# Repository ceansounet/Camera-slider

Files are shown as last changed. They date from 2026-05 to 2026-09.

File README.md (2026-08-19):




# Camera-Slider
This project is a camera slider, useful to take smooth video shots, long moving timelapses, repeatable movement for special effect shots and much more.

## Features : 
- 2 motors for translation and rotation
- Compatible with phone control and a custom controller
- Saving points and playing them back
- Custom speed curves
- A ton of possible shots : timelapse, special FX overlaying, object tracking.
- usb-c charging for both, the slider is compatible with any usb-c battery bank (~20W peak)

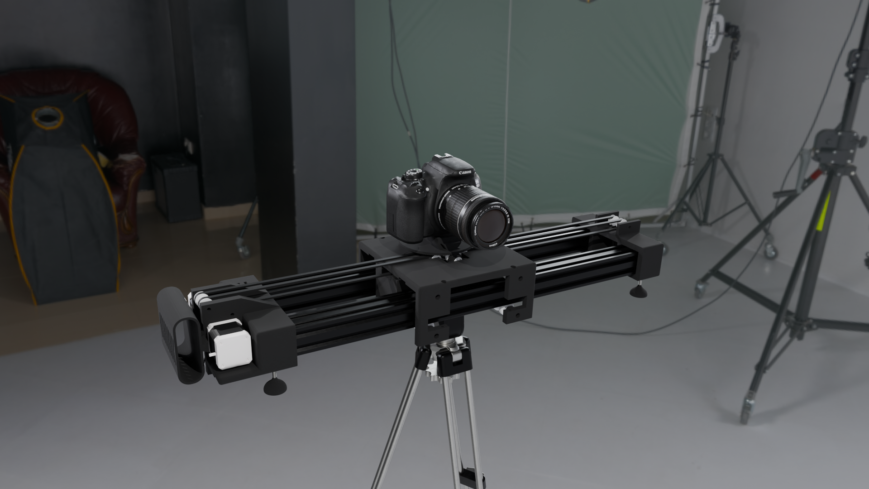
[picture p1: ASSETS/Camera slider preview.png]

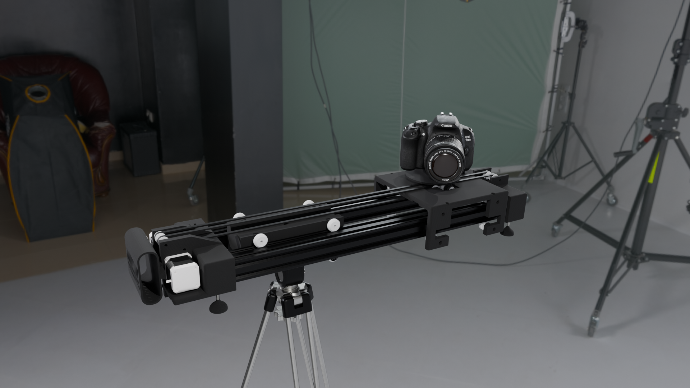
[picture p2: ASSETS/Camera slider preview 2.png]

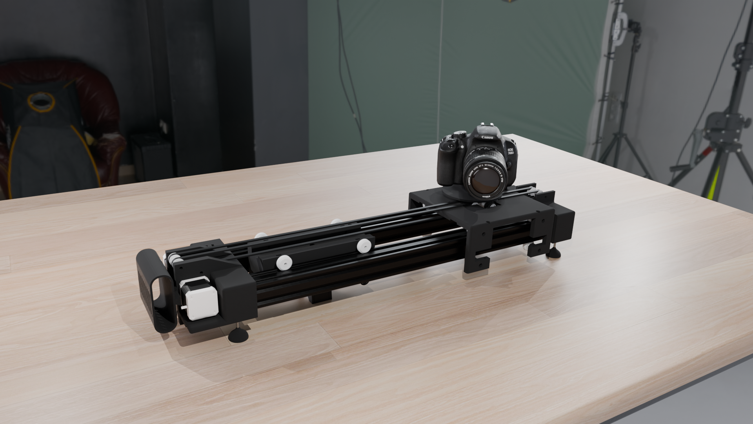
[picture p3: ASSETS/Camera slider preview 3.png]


## Workflow :
- connect
- Set 2 points or more by hand
- choose speed curves (or leave the default one)
- choose the kind of shot wanted
- start recording
- press play

## here is a youtube playlist with all of my work sessions :
[Camera-Slider Playlist](https://www.youtube.com/watch?v=zh-EyJo-g44&list=PLc9wTLk_Nb17q8Yq_pcCUll0olrOZS_lk&pp=0gcJCcwEOCosWNinsAgC)

Main CAD file :



Cut view of the slider :



PCB for the slider :



Controller CAD :



Main PCB for the controller :



Second controller PCB : 



Exploded shot GIF for Assembly : 

## Tech used :

CAD - Solidworks + Grabcad

PCB - Kicad

Code - VScode + ESP IDF addon

## Videos and pictures of the build :



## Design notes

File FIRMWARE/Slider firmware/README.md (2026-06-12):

# MotionCtrl — Firmware ESP32-S3

Contrôleur de 2 moteurs pas-à-pas (A4988) avec interface web WiFi et manette déportée.

---

## Architecture

```
motionctrl/              ← Firmware unité principale
├── main/
│   ├── main.c           ← Point d'entrée, init, boucle watchdog
│   └── config.h         ← Tous les pins & constantes
└── components/
    ├── stepper/         ← Driver A4988 (esp_timer ISR, rampe accél)
    ├── motion_planner/  ← Points, séquences, effets, NVS
    ├── wifi_ap/         ← Point d'accès WiFi
    ├── webserver/       ← HTTP + WebSocket, UI embarquée
    └── controller_link/ ← UART vers manette (JSON framé)

motionctrl_controller/   ← Firmware manette
└── main/main.c          ← Joysticks, boutons, écran, UART
```

---

## Câblage unité principale

| Signal | GPIO |
|---|---|
| M1 DIR | 1 |
| M1 STEP | 2 |
| M1 ENABLE | 3 |
| M2 DIR | 4 |
| M2 STEP | 5 |
| M2 ENABLE | 6 |
| ENDSTOP | 13 |
| UART TX → manette | 17 |
| UART RX ← manette | 18 |

> A4988 : ENABLE actif à l'état BAS. Le firmware gère le HIGH/LOW automatiquement.
> ENDSTOP : connecte la broche à GND quand déclenché (pull-up interne activé).

---

## Câblage manette (ESP32-S3)

| Signal | GPIO |
|---|---|
| Joystick 1 X | 1 (ADC1_CH0) |
| Joystick 1 BTN | 3 |
| Joystick 2 X | 4 (ADC1_CH3) |
| Joystick 2 BTN | 6 |
| BTN STOP | 7  |
| BTN HOME | 8  |
| BTN RUN | 9  |
| BTN MENU | 16 |
| UART TX → principale | 17 |
| UART RX ← principale | 18 |
| Écran BL PWM | 15 |
| Écran SPI MOSI | 11 |
| Écran SPI SCLK | 12 |
| Écran CS | 10 |
| Écran DC | 13 |
| Écran RST | 14 |

---

## Compilation et flash

### Prérequis
- ESP-IDF v5.1+
- `idf.py` dans le PATH

### Unité principale
```bash
cd motionctrl
idf.py set-target esp32s3
idf.py build
idf.py -p /dev/ttyUSB0 flash monitor
```

### Manette
```bash
cd motionctrl_controller
idf.py set-target esp32s3
idf.py build
idf.py -p /dev/ttyUSB1 flash monitor
```

---

## Utilisation

1. **Allumer l'unité principale** → crée le réseau WiFi `MotionCtrl` (mdp: `motionctrl123`)
2. **Connecter le téléphone** à ce réseau
3. **Ouvrir** http://192.168.4.1 dans le navigateur

### Interface web – onglets

| Onglet | Fonctionnalité |
|---|---|
| **Jog** | Déplacement manuel moteur par moteur, homing, enable/disable |
| **Points** | Sauvegarder la position courante, lister, naviguer, supprimer |
| **Séquence** | Ajouter des points dans un ordre, choisir vitesse/pause/courbe d'accélération, lancer/pause/stop |
| **Effets** | Hyperlapse, Oscillation, Pendulum – configurer et lancer |

### Courbes d'accélération disponibles
- **Linéaire** : rampe constante
- **Ease In** : démarrage doux, freinage brusque
- **Ease Out** : démarrage brusque, freinage doux
- **Ease In/Out** : courbe S symétrique
- **Bézier** : smooth step (smoothstep cubique)

### Effets
| Effet | Description |
|---|---|
| **Hyperlapse** | Déplace en N positions équidistantes entre A et B, avec pause configurable entre chaque → parfait pour timelapse |
| **Oscillation** | Fait des allers-retours entre deux points, avec pause aux extrémités |
| **Pendulum** | Mouvement sinusoïdal entre deux points, vitesse variable naturellement |

### Manette physique
| Contrôle | Action |
|---|---|
| Joystick 1 | Jog Moteur 1 (proportionnel) |
| Joystick 2 | Jog Moteur 2 (proportionnel) |
| BTN STOP | Arrêt immédiat des moteurs |
| BTN HOME | Homing Moteur 1 |
| BTN RUN | Lancer la séquence |
| BTN MENU | Changer d'écran |
| JOY1 BTN  | Pause / Reprendre |

---

## Personnalisation

### Mécanique (config.h)
```c
#define DEFAULT_STEPS_PER_MM    80     // steps/mm selon votre mécanique
#define DEFAULT_MAX_SPEED_MM_S  100.0  // vitesse max mm/s
#define DEFAULT_ACCEL_MM_S2     200.0  // accélération mm/s²
```

### Changer le mot de passe WiFi
```c
#define WIFI_AP_PASS  "votre_mot_de_passe"
```

### Ajouter un driver d'écran (manette)
Remplacer la fonction `display_render()` dans `motionctrl_controller/main/main.c` par votre driver LCD (LVGL, TFT_eSPI, esp_lcd, etc.).

---

## Protocole UART (unité principale ↔ manette)

Frame : `[STX=0x02][LEN_HI][LEN_LO][JSON][ETX=0x03]`

### Commandes → unité principale
```json
{"cmd":"J","motor":0,"steps":100,"speed":10.0}   // Jog
{"cmd":"S"}                                        // Stop
{"cmd":"H","motor":0}                              // Home
{"cmd":"G","idx":2,"speed":15.0}                   // Goto point
{"cmd":"R"}                                        // Run sequence
{"cmd":"P"}                                        // Pause
{"cmd":"r"}                                        // Resume
```

### Status ← unité principale (push 200ms)
```json
{"state":"idle","m1_pos":1234,"m1_run":false,"m2_pos":567,"m2_run":false,"endstop":false}
```

---

## Notes importantes

- **Endstop** : le firmware déclenche un `stepper_stop_all()` sur interruption GPIO (front descendant). Si vous utilisez l'endstop pour le homing uniquement, vous pouvez retirer l'ISR dans `main.c`.
- **Microstepping** : le firmware compte en steps bruts. Ajustez `DEFAULT_STEPS_PER_MM` selon votre microstepping (1/16, 1/8, etc.).
- **La persistance NVS** sauvegarde automatiquement les points et séquences — ils survivent aux redémarrages.
- **Sécurité** : pas d'authentification sur l'interface web (réseau local isolé).

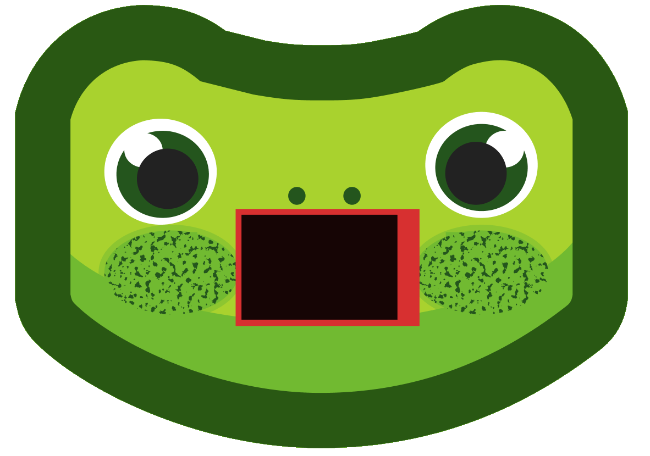
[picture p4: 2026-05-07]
ASSETS/FROG STICKER.png

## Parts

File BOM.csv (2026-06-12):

Item | Description | Quantity | Unit Price | Shipping | Total price | Total price ($) | product link
Nema 17 stepper motor | 17HE19-2004S from stepper online | 2 | 8,64€ | 9,29€ | 26,57€ | $30,75 | Série E Nema 17 Bipolaire 55Ncm(77.88oz.in) 2A 42x48mm 4 Fils avec 1m Câble & Connecteur - 17HE19-2004S|STEPPERONLINE
Aluminium extrusions | 1m double V-slot 4040 | 2 | 27,68€ | 14,12€ | 69,48€ | $80,40 | Profilé aluminium V-SLOT 40x40 fente 6 mm - Anodisé noir
Battery bank | 12v 1,5 amps minimum, any will do | 1 | 19,99€ | 0€ | 19,99€ | $23,13 | VARMFRONT chargeur mobile universel, bleu foncé, 10400 mAh - IKEA
18650 li ion batterie | 3,6v 3180mAh | 2 | 3,29€ | 4,10€ | 10,68€ | $12,36 | Panasonic NCR18650BD 3180mAh - 10A
12v to 5v Buck converter | for the slider control board | 1 | 2,79€ | 0€ | 2,79€ | $3,23 | https://www.aliexpress.com/item/1005006151233979.html?mp=1
3,5 inch TFT screen | screen, non touch | 1 | 8,89€ | 0€ | 8,89€ | $10,29 | https://www.aliexpress.com/item/1005004903996715.html?mp=1
Joystick | XY joysticks to control the slider | 2 | 1,71€ | 0€ | 3,42€ | $3,96 | https://www.aliexpress.com/item/1005007039932732.html?mp=1
ESP32 S3 supermini | Dev boards | 2 | 4,49€ | 0€ | 8,98€ | $10,39 | https://www.aliexpress.com/item/1005007941259180.html?mp=1
IO expander | MCP 23017 | 1 | 2,17€ | 0€ | 2,17€ | $2,51 | https://www.aliexpress.com/item/1005008066849865.html?mp=1
Cherry MX switches | 10 pack of gateron yellow 3.0 | 1 | 3,19€ | 0€ | 3,19€ | $3,69 | https://www.aliexpress.com/item/1005006376024657.html?mp=1
USB PD board | for 12v power | 1 | 4,59€ | 0€ | 4,59€ | $5,31 | https://www.aliexpress.com/item/1005008209411188.html?mp=1
M5 locknuts | 25 pack | 1 | 1,89€ | 0€ | 1,89€ | $2,19 | https://www.aliexpress.com/item/32798773566.html?mp=1
v-slot wheels | 24 pack (only need 16) | 1 | 17,69€ | 0€ | 17,69€ | $20,47 | https://www.aliexpress.com/item/1005005890959821.html?mp=1
M4*90mm | 10 pack (only need 4) | 1 | 4,49€ | 0€ | 4,49€ | $5,20 | https://www.aliexpress.com/item/1005002270744409.html?mp=1
End stop switch | 10 pack, only need 1 | 1 | 1,59€ | 0€ | 1,59€ | $1,84 | https://www.aliexpress.com/item/32939882024.html?mp=1
Ball bearings | 10 pack, only need 4 | 1 | 3,89€ | 0€ | 3,89€ | $4,50 | https://www.aliexpress.com/item/1005007668446060.html?mp=1
GT2 Idler Pulley | 2*6 pack, need 10 | 2 | 5,79€ | 0€ | 11,58€ | $13,40 | https://www.aliexpress.com/item/1005007557987612.html?mp=1
GT2 teethed pulley | 5 pack, only need 3 | 1 | 3,19€ | 0€ | 3,19€ | $3,69 | https://www.aliexpress.com/item/32781681772.html?mp=1
1/4" nut | 20 pack, need 1 | 1 | 4,09€ | 0€ | 4,09€ | $4,73 | https://www.aliexpress.com/item/1005009774349007.html?mp=1
GT2 belt | 5 meters 6mm | 1 | 11,69€ | 0€ | 11,69€ | $13,53 | https://www.aliexpress.com/item/1005010116034089.html?mp=1
1/2" 1/4" screw | UNC screws, for camera, only need 1 | 1 | 2,09€ | 0€ | 2,09€ | $2,42 | https://www.aliexpress.com/item/1005005237204588.html?mp=1
2" 1/4" screw | UNC screws, for tripod, only need 1 | 1 | 4,09€ | 0€ | 4,09€ | $4,73 | https://www.aliexpress.com/item/1005005237204588.html?mp=1
1/4" 50mm coupling nut | UNC nut, for tripod | 1 | 6,79€ | 2,09€ | 8,88€ | $10,28 | https://www.aliexpress.com/item/1005008622413040.html?mp=1
Battery holder | 2 parallel battery holder | 1 | 1,49€ | 0,00€ | 1,49€ | $1,72 | https://www.aliexpress.com/item/1005003099571328.html?mp=1
Main slider PCB | pack of 5, need 1 | 1 | 1,73€ | 8,48€ | 10,21€ | $11,81 | https://cart.jlcpcb.com/shopcart/cart
Main controller PCB | pack of 5, need 1 | 1 | 3,46€ | 0€ | 3,46€ | $4,00 | https://cart.jlcpcb.com/shopcart/cart
Controller keys PCB | pack of 5, need 2 | 1 | 3,46€ | 0€ | 3,46€ | $4,00 | https://cart.jlcpcb.com/shopcart/cart
Resistors | 4.7Kohm | 2 | 0€ | 0€ | 0,00€ | $0,00 | I already have those but you can find them anywhere on aliexpress
Capacitor | 100nF decoupling cap for the IO expander | 1 | 0€ | 0€ | 0,00€ | $0,00 | I already have those but you can find them anywhere on aliexpress
Capacitor | 100uF decoupling cap for the motors | 1 | 1,83€ | 0€ | 1,83€ | $2,12 | 10V 16V 25V 35V 50V 400V 450V DIP Aluminum Electrolytic Capacitor 100UF 220UF 330UF 470UF 680UF 1000UF 10UF 22UF 47UF 0.47UF - AliExpress 502
Elegoo PLA Matte | ~500g | 1 | 17,99€ | 15€ | 32,99€ | $38,18 | ELEGOO PLA MATTE Filament 1.75mm Colored 1KG
Elegoo PETG rapid | ~1,3kg, rolls of 1kg | 2 | 13,99€ | 0€ | 27,98€ | $32,38 | RAPID PETG – ELEGOO FR
TOTAL : |  |  |  |  | 256,36€ | $296,66

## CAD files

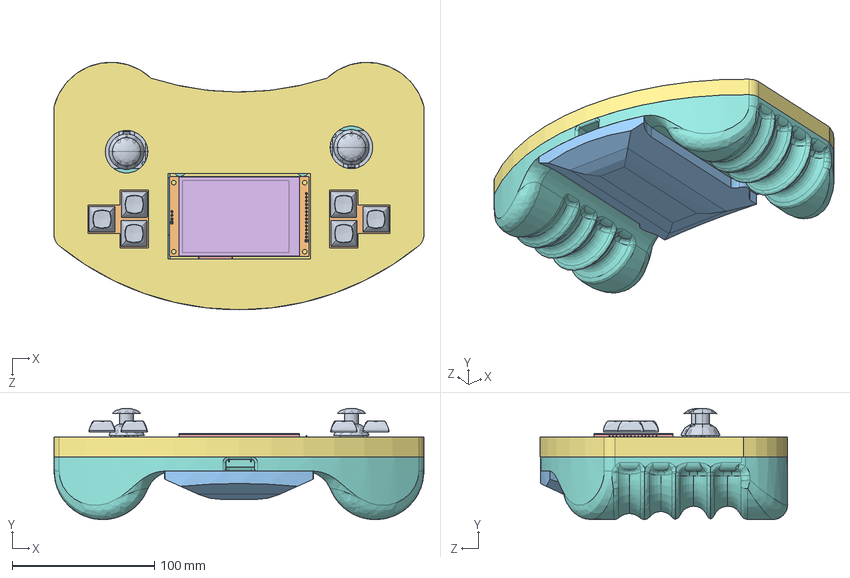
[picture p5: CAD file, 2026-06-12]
CAD/Full controller assembly.STEP
260.0 x 78.2 x 173.9 mm
PinHeader_1x04_P2.54mm_Vertical_1.step x 2
PinHeader_1x05_P2.54mm_Vertical.step x 2
C_Disc_D5.0mm_W2.5mm_P5.00mm.step
DIP-28_W7.62mm.step
PinHeader_1x09_P2.54mm_Vertical.step x 2
R_Axial_DIN0207_L6.3mm_D2.5mm_P7.62mm_Horizontal.step x 2
controller_PCB.step
Case bas^controller
Joystick HW504 Board_Varsayılan x 2
TFT SPI Serial LCD Module 480X320 Driver IC ILI9488_XPT2046_MSP3520_По умолчанию
card sd_Valor predeterminado
microSDCard_По умолчанию
contact01.step_По умолчанию
contact02.step_По умолчанию
contact03.step_По умолчанию
contact04.step_По умолчанию
contact05.step_По умолчанию
contact06.step_По умолчанию
contact07.step_По умолчанию
contact08.step_По умолчанию
frame.step_По умолчанию
contact09.step_По умолчанию
cover.step_По умолчанию
contact11.step_По умолчанию
contact10.step_По умолчанию
Штыревой разъем 14 конт шаг 2.54мм_По умолчанию
screen spacer^controller x 4
Top cover^controller
MX Mount v1.step x 6
eBom-FreeParts.step x 6
PinHeader_1x04_P2.54mm_Vertical.step x 2
keys_PCB.step x 2
Back cover^controller

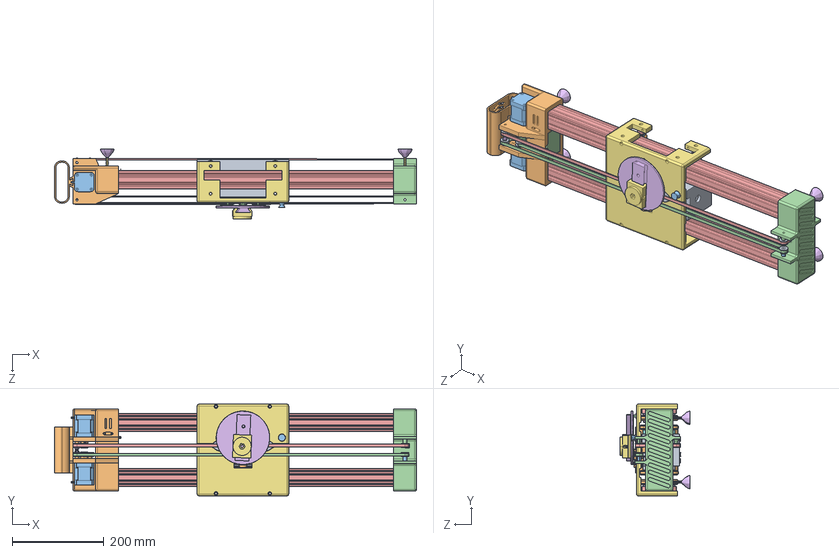
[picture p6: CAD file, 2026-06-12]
CAD/Full slider assembly.STEP
790.0 x 200.0 x 152.5 mm
Left End cap^slider assembly
Right end cap^slider assembly
Camera carriage^slider assembly_Défaut<Brut d''usinage>
Under carriage tripod mount^slider assembly
Solid V-Wheel.stp x 16
Ball Bearing 625 2RS 5x16x5.stp x 32
1mm 5mm shim.stp x 16
aluminium 4040 vslot Extrusions^slider assembly_Défaut<Brut d''usinage>
M5 Nylock.ipt x 4
1-4-20unc nut_95462A029
¼-20 x 1.ipt
GT2 sin dientes_Predeterminado x 11
GT2 Timing Pulley x 3
NEMA17_17HS19-2004S1_Stepperonline_По умолчанию x 2
Bearing 625 ZZ x 6
Copy of Bearing holder 2^Bearing assembly_slider assembly x 3
Copy of Feets^Assemblage2_slider assembly x 4
bolt x 4
M5 nut x 4
Copy of Timing belt holder^slider assembly x 4
Copy of Copy of Bearing holder 2^slider assembly
Copie (2) de Copy of Bearing holder 2^slider assembly
Bearing holder^slider assembly x 2
Bearing shim^slider assembly
Gear A^slider assembly
Camera rotary platform^slider assembly
Camera mount^slider assembly
Limit_Switch_L1
Battery holder^slider assembly
cable holder
PCB LID^slider assembly
PinHeader_1x09_P2.54mm_Vertical.step x 2
PinHeader_1x04_P2.54mm_Vertical.step x 3
PinHeader_1x02_P2.54mm_Vertical.step x 2
C_Disc_D5.0mm_W2.5mm_P5.00mm.step
SLIDER_PCB_REV_A_PCB.step
Travel lock^slider assembly
Courroie1-8^slider assembly
Courroie2-9^slider assembly

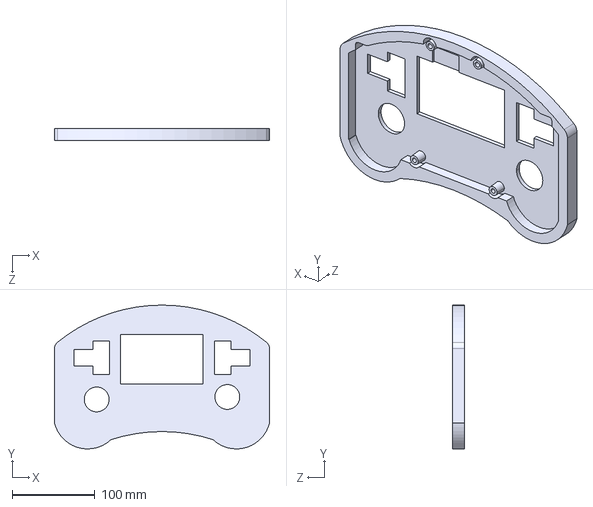
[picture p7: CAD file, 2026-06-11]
CAD/Controller/STLS/Top cover.STEP
260.0 x 173.9 x 14.0 mm

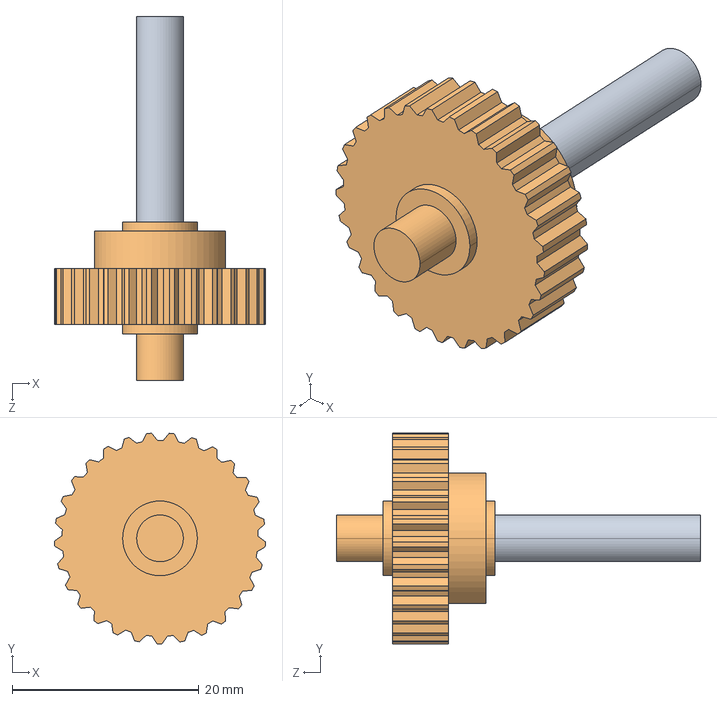
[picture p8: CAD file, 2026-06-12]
CAD/Slider/STEPs/Gear A.STEP
22.6 x 22.6 x 39.0 mm

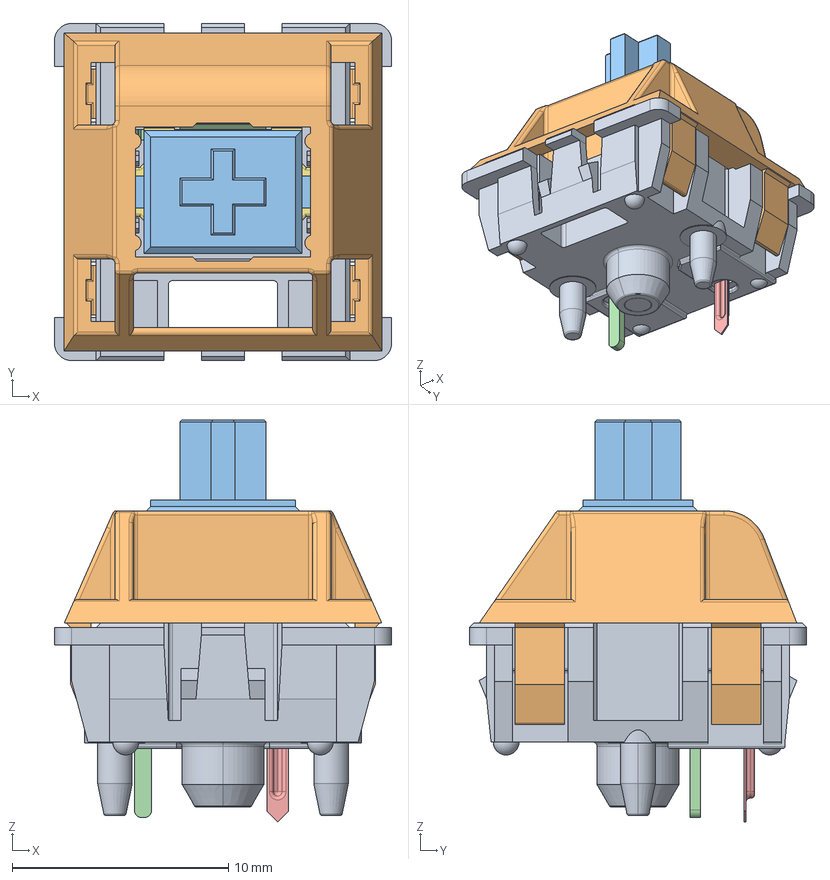
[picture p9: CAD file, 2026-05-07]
PCB/CONTROLLER_PCB_REV_A/keys/SW_Cherry_MX_1.00u_PCB.step
15.6 x 15.6 x 18.6 mm

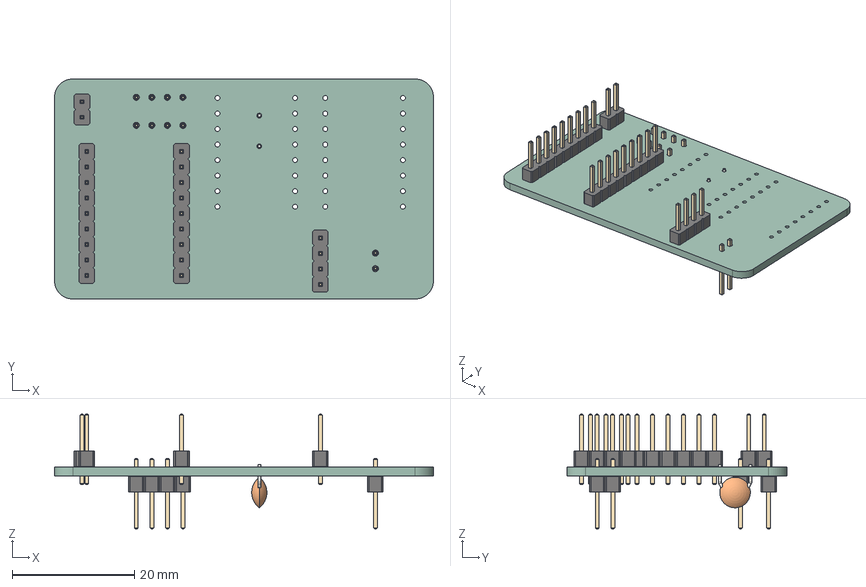
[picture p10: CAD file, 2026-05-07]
PCB/SLIDER_PCB_REV_A/SLIDER_PCB_REV_A.step
62.0 x 36.0 x 18.8 mm
PinHeader_1x09_P2.54mm_Vertical x 2
PinHeader_1x04_P2.54mm_Vertical x 3
PinHeader_1x02_P2.54mm_Vertical x 2
C_Disc_D5.0mm_W2.5mm_P5.00mm
SLIDER_PCB_REV_A_PCB

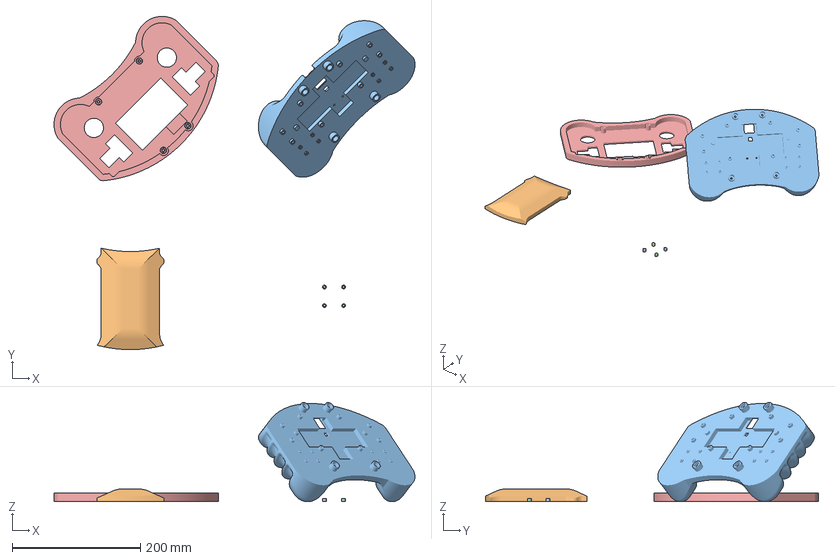
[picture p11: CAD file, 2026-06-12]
PRODUCTION/CONTROLLER 3D PRINTS/Controller prints project.3mf
562.9 x 519.6 x 155.1 mm
screen spacer x4.STEP x 4
Back cover.STEP
Case bas.STEP
Top cover.STEP

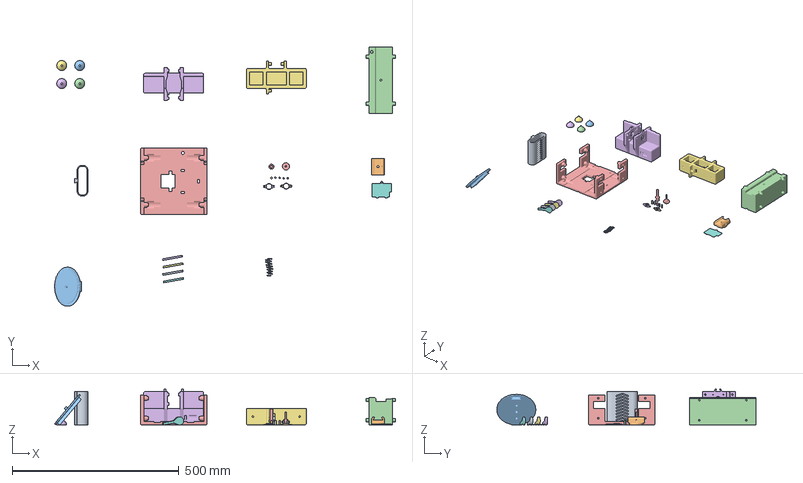
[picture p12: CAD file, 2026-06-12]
PRODUCTION/SLIDER 3D PRINTS/Slider prints project.3mf
1022.7 x 777.6 x 107.5 mm
Copy of Timing belt holder x2.STEP x 4
Bearing holder x2.STEP x 2
feets x4.STEP x 4
Travel lock.STEP
PCB LID.STEP
Battery holder.STEP
Camera mount.STEP
Camera rotary platform.STEP
Under carriage tripod mount.STEP
Camera carriage.STEP
Left End cap.STEP
Right end cap.STEP
Bearing holder little x5.STEP x 5
cable holder x14.STEP x 14
Gear A.STEP

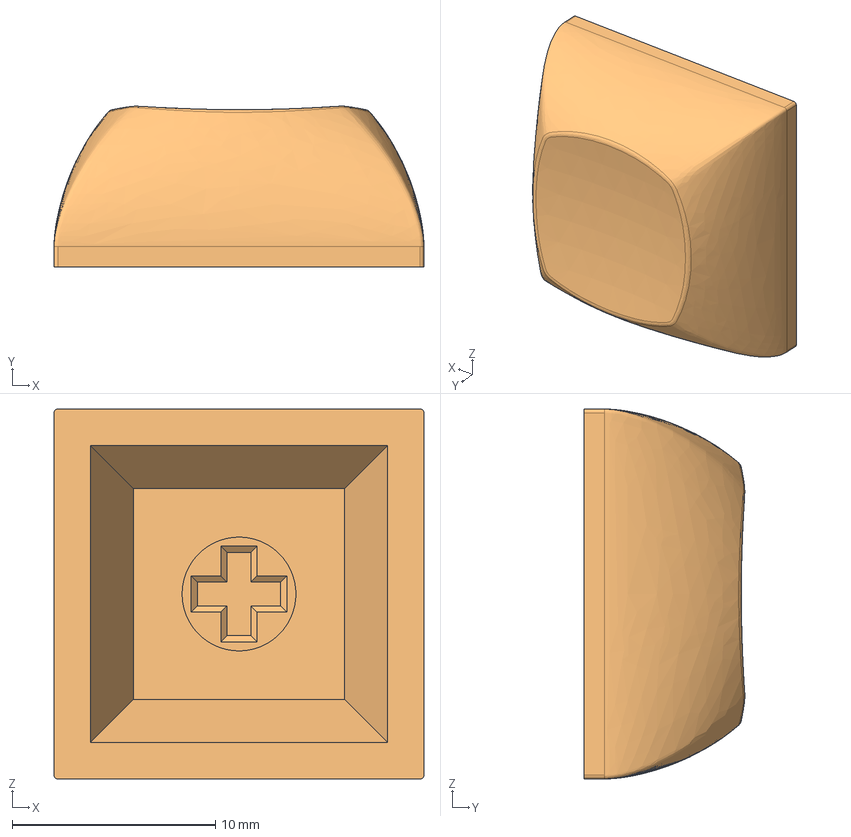
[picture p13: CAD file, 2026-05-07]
CAD/Controller/DSA 1u.step
18.2 x 7.91 x 18.2 mm

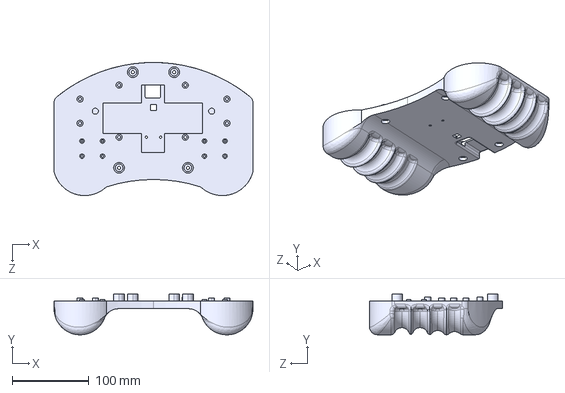
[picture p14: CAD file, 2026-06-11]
CAD/Controller/STLS/Case bas.STEP
260.0 x 53.1 x 173.9 mm

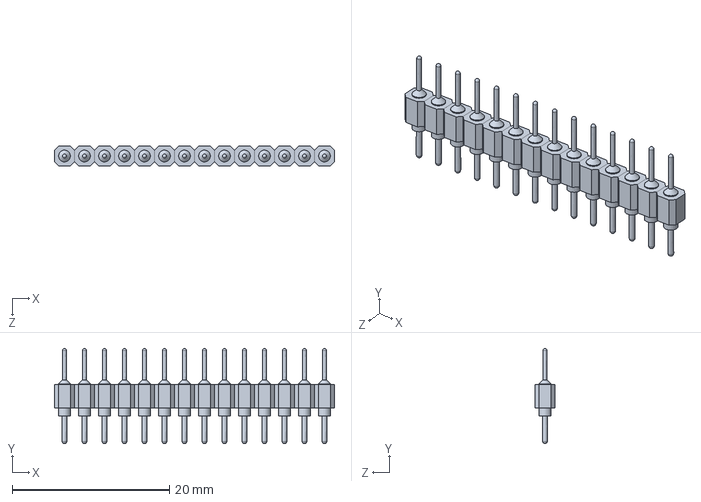
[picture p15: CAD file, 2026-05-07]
CAD/Controller/tft-spi-serial-lcd-module-480x320-driver-ic-ili9488-xpt2046-msp3520-1.snapshot.1/Штыревой разъем 14 конт шаг 2.54мм.SLDPRT
35.6 x 12.1 x 2.54 mm

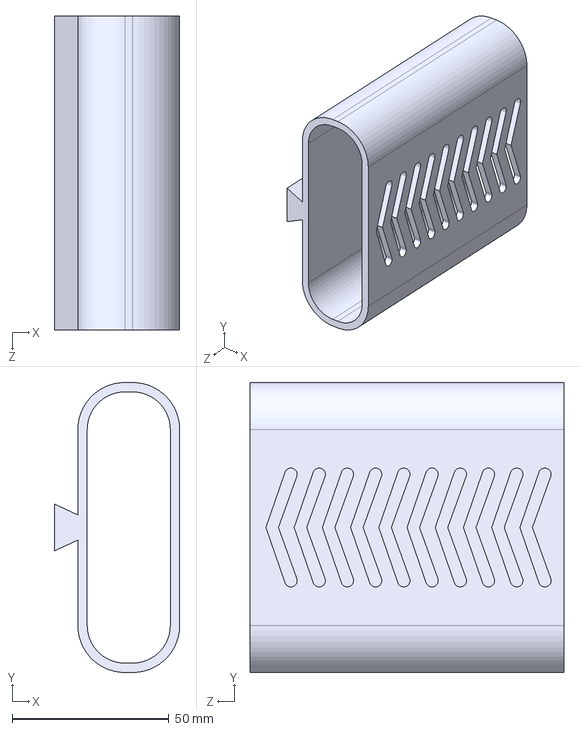
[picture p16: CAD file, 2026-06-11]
CAD/Slider/STEPs/Battery holder.STEP
40.0 x 92.5 x 100.0 mm

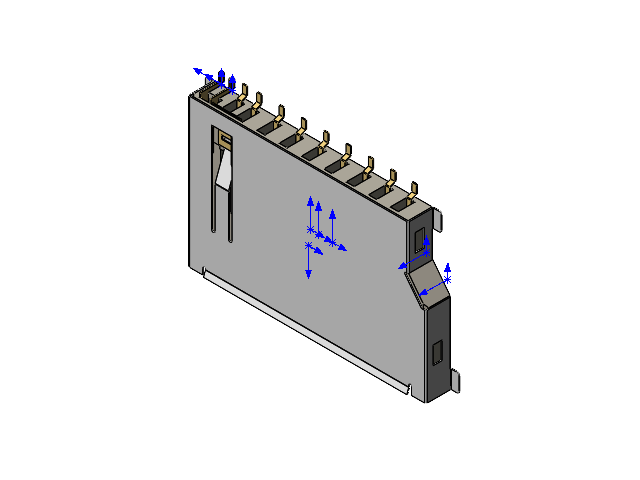
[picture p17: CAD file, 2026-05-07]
CAD/Controller/tft-spi-serial-lcd-module-480x320-driver-ic-ili9488-xpt2046-msp3520-1.snapshot.1/Slot_SD-381200-S304.SLDASM
contact01.step
contact02.step
contact03.step
contact04.step
contact05.step
contact06.step
contact07.step
contact08.step
frame.step
contact09.step
cover.step
contact11.step
contact10.step

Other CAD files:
CAD/Slider/slider assembly.SLDASM
CAD/Controller/DSA V4 1x1 v4_2.step.SLDASM
CAD/Controller/DSA V4 1x1 v4_1.step.SLDASM
CAD/Controller/MX Mount v1_2.step.SLDPRT
PCB/CONTROLLER_PCB_REV_A/controller/SW_Cherry_MX_1.00u_PCB_1.step.SLDPRT
CAD/Controller/Joystick HW504 Board.SLDPRT
CAD/Controller/MX Mount v1_1.step.SLDPRT
CAD/Controller/PinHeader_1x04_P2.54mm_Vertical_1.step.SLDPRT
CAD/Controller/STLS/Back cover.STEP
CAD/Controller/STLS/screen spacer x4.STEP
CAD/Controller/controller.SLDASM
CAD/Controller/controller.step
CAD/Controller/eBom-FreeParts_1.step.SLDPRT
CAD/Controller/eBom-FreeParts_2.step.SLDPRT
CAD/Controller/keys.step
CAD/Controller/keys_PCB_1.step.SLDPRT
CAD/Controller/tft-spi-serial-lcd-module-480x320-driver-ic-ili9488-xpt2046-msp3520-1.snapshot.1/TFT SPI Serial LCD Module 480X320 Driver IC ILI9488_XPT2046_MSP3520.SLDASM
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

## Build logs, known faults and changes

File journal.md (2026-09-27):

# May 1st, 2026: First day, started CAD !

I spent this first session doing some of the CAD for the slider assembly, this is pretty complex and I want it to be modular so I learnt a lot about global variables in solidworks, so that each parameter can be adjusted freely.
I spent a lot of time sketching for this project during class (yes, I know that I should be paying attention but philosophy is boring), so I had a pretty good idea of what I wanted to do, I looked at some existing camera sliders and either the camera couldn't rotate, or it was with an additional tool, so my idea was to combine everything into one, using of the shelf parts, instead of carbon fiber rods or weird unfindable aluminium profiles, I use simple 4040 extrusions, with double v-slots, my design is kinda inspired by eldekrone's sliderplus-v6 in the movement aspect, as it is the only one I have seen that can travel almost 2 times it's own lenght (only on a tripod) by being mounted on a moving carriage, that goes in the opposite direction as the camera.



**Total time spent: 2h17**

# May 2nd, 2026: Added feets !

In this second session I expanded on my previous design session, I made the early sketch of the under carriage that will get mounted on the tripod, and I made feets that house an M5 bolt with an embedded M5 nut, I modified the end caps accordingly to allow for those feets to screw in, and give a flexible way to adjust the slider's level.
I also took the time to adjust the main carriage's height, because it was a bit too high, and added some groves for the wheels to fit with that lowered part.



**Total time spent: 2h9**

# May 3rd, 2026: Still doing CAD !

For this short third session, I started with journaling the second session, then I did some CAD work, I added slots to insert locknuts for the v slot wheels to attach to the undercarriage.
I also did some research on how tripod screws work, so that I can attach my slider to a tripod, I want it to be extremely secure, as when it is fully extended, the forces are quite big, so I decided to go with a really long nut, a coupling nut, with a bolt on the other side to make sure it doesn't go anywhere.
I wondered about adding bolts that go through the under carriage, like in the camera carriage, to either adjust the wheels, and add a lot of strenght, but I decided against it for now, in my inspiration, the edelkrone sliderplus v6, they are present, but I am not sure if they are absolutely necessary, and I want to reduce bloat and hardware.
If I do come to regret this, I can just make another version and 3d print it again, and maybe even try a cf or gf reinforced filament.



**Total time spent: 1h13**

# May 4th, 2026: Movement, belts, the whole enchilada !

I just finished session 4, today I worked on the belt system.
I was kind of afraid of starting to work on it but as always, it wasn't too bad.
I managed to find 3d models for my stepper motors, timing and idler pulleys, both at gt2 20T 6mm, which I guess is the most common, used for 3d printers and such.
then I made a mount on one of my end caps for the motors, then for the idler pulleys. I think I will have to reinforce the different parts later on, and clean up the geometry to make it look good.



**Total time spent: 1h45**

# May 5th, 2026: Attaching the timing belts

During session 5, I added another idler pulley at the bottom, and started to work on the mounting system between the sliders and the timing belts.



**Total time spent: 1h06**

# May 6th, 2026: Attaching the timing belts again (with the bottom this time)

In this 6th session I added the slot for the GT2 6mm timing belt, and I added an attachment point for the undercarriage as well.



**Total time spent: 1h02**

# May 7th, 2026: I cooked some CAD again

In this seventh session, I designed a whole bunch of stuff :
- added/changed the rotation belt path
- added the rotation mechanism
- made the camera platform, with an added dovetail to adjust the center of mass of the camera
- made the dovetail mount
- solved a lot of small misc issues



**Total time spent: 5h02**

# May 8th, 2026: Stablizing the platform, and preparing pcb space !

During this eighth session, I added 2 bearings for stabilization under the camera platform, I then added an endstop where I will try to fit all of the electronics.
I added groves for the future PCB.
Then I added recesses for the motor wires, with little slots for cable holders.
After that was done I modeled a case for the battery, with a dovetail, and I added the opposite dovetail to the left end cap to attach it.
Seeing all of my progress, I started to work on the aestetics of my build, by adding a lot of fillets on all of the parts, and sourced 4 screws that I forgot while designing (I almost payed 10$ for 4, but I managed to find some for 5$) and I also sourced a usb-c port, and I added a slot for it on my design.






**Total time spent: 2h28**

# May 9th, 2026: Finished the CAD (1st version at least) !

In this ninth session, I pretty much finished up the CAD, did some measurements to get the lenght of GT2 belts I need, and then I moved on to the PCB, I managed to find the symbols I needed, and made a footprint for the esp.
I'm quite scared as it is going really fast, and I'm only at around the 20hr mark, I know I have some stuff left to do but I counted almost everything I need and I'm at around 170€, or exactly 200$. which is 40hrs of work, the cheapest aluminium extrusions I found are 70€ total, with shipping, and the rest of the parts add up to 100€ from aliexpress.



**Total time spent: 1h08**

# May 10th, 2026: Doing the PCB ! 

During this tenth session, I almost finished the PCB, I am still missing the routing but all of the rest is done.
I made a lid for the pcb and electronics in the cad, and I added a hole that will have a pin, used to lock the carriages together for transport.



**Total time spent: 1h47**

# May 11th, 2026: Finishing the PCB !

in this eleventh session I continued on my previous work, I finished the pcb layout and did the routing, then I finished the pin that can lock both carriages together for transport, and added magnets at the end so it's secure, and made a small storage hole for it, then I made the belts that allow the movement, and when they were done I realised that they were interfering with the usb c port location, so I moved that.




**Total time spent: 1h40**

# May 12th, 2026: Starting the controller !

This is the 12th session I believe, today I started research on the controller that I want to design, and maybe make if the budget allows, for the camera slider.
I used google and AI to do some preliminary research, while always reviewing it's claims with datasheets, forums, and common sense.
I started to source the different parts that I need, and started work on the PCB, it has a lot in common with the hackpad that I made, so I took some parts from it, but sadly this is very fast, so the plan of taking some time to design a cheap controller to have more budget for the slider isn't really going to plan...
I think the final steps of doing the github, bom, exporting everything, the zine, and most importantly the code, are vastly underestimated by myself, so there is hope that I reach the ~45-60hrs I need to finance it.
(now that I think about it, I have to code dialog between 3 esp's, and a phone, over wifi, and also make a cool interface for the website, and another one for the controller, and also code every feature by hand...)



**Total time spent: 1h16**

# May 13th, 2026: Research for the controller !

Today I did more research and planning and pcb for the controller, my previous plan kinda went overboard when I realized that the parts I was looking for kinda weren't real.
So I switched my approach to use joysticks instead, just like a drone controller.



**Total time spent: 1h11**

# May 14th, 2026: Controller PCB 

Hey, during this short 14th session I worked on the controller pcb again, I realized that pcb costs were really high for larger than 100*100mm pcb's, so I thought of a clever plan, doing 2 different pcb's, and connecting them with cables, and the second pcb will be present twice in the final build, because I get 5 per order anyway.



**Total time spent: 2h17**

# May 15th, 2026: Moved some PCB stuff around because of KiCAD

Session 15, here we go !
I continued working on the controller for the slider, I spend more time that I would like to admit on a problem, that is a limitation of kicad, every pcb has to have a project file, you can't really have 2 pcb's in a single project file.
So I had to make a new project file for the key pcb's, and modify the old one to remove the keys, so that took a while.
Then I started to work on the CAD for the controller, I exported the pcb's in step and made a sketch for the controller's over all shape. That's it for today, I don't really know how I can make it ergonomic in solidworks, but I'll try anyway. Oh and if I don't see ya, good afternoon, good evening and goodnight !



**Total time spent: 1h03**

# May 16th, 2026: Bday + Controller CAD

Session 16 ! today I celebrated my birthday, yay ! but that also means I didn't have much time to work...
Today I continued on my controller journey, I modified a bit the pcb's because they were incorrect, then I made all of the stands for the pcb's, after that was done, I found a 3d model of the screen I'm using, so I added that, and also made little standoffs so that the screen doesn't flex.
In the end I started to try and make an ergonomic shape for the controller, but that proved to be kinda hard...



**Total time spent: 1h09**

# May 17th, 2026: Ergonomics is hard ! :pf:

Session 17... this one was a bad one. I spent the whole hour fighting against solidworks to try and make ergonomic handles for the controller, they still don't look really good, but I will have to try them to see how they can be improved.



**Total time spent: 1h07**

# May 18th, 2026: Solidworks recovery, and added keycaps !

Today started on a bad note... on top of the site being down my solidworks controller assembly wouldn't open, and when it did, all of the dependencies had to be replaced, that meant also replacing every constraint :pf:.
But apart from that, I managed to make a little progress, added the keycaps, made holes for the pcb pins to have room, and for the overall controller to be slimmer, next time I can start on the top cover.



**Total time spent: 1h05**

# May 19th, 2026: Solidworks is still mad at me !

The nineteenth session started as usual with this file, with all the step files being reverted, and all of the constraints being removed, after quickly fixing that, I started work on the top part, and pretty much finished it, apart from some art that I want to make for it.
(also, it looks like a happy frog when upside down!)



**Total time spent: 1h17**

# May 20th, 2026: I'm also an artist !

20th session, :YAY: today I did some art, it's pretty mediocre but it's still art.
I made a frog sticker that goes on the controller, because I think it looks like a frog when upside down, then I made some changes to the github page, I'm still ways to the end, but I need to keep pushing, next sessions will probably be short as well, because of school stuff, but next week I have a 4 day weekend all alone, I think I can do my own hackaton and cram as many hours as possible !



**Total time spent: 1h04**

# May 21st, 2026: Boring BOM stuff

Today I worked on my BOM, and started to realise how much this project was actually gonna cost (ouch).
I also started to think about the camera head, and what I need to buy for it. (in the end, I decided to split my project, because this is too ambitious for a single project to do both, and the opensauce budget is fixed)



**Total time spent: 1h07**

# June 11th, 2026: Back to it ! 

I finally came back to this project ! I had to get back into it so I did some CAD, for the Battery pack of the controller, and I worked on the github.



**Total time spent: 2h31**

# June 12th, 2026: Submission day !

Final day (before the first submission) ! I'm basically done, I finished up the BOM, made a blender scene for the project, finished the readme, and made all of the 3d printing files for it. (about 2kg of PETG and PLA, over 50 hours and 15 build plates !)



**Total time spent: 1h54**

# July 3rd, 2026: Building

All of the parts have finally arrived, I started by cutting off a bit of the aluminium extrusions, else it wouldn't fit in my luggage to SF, then I had the painstaking process of post processing all of the printed parts, which took a while with all of the supports and the brims.
I soldered the pcbs with the components needed, but when I tried testing them, I realised both of the esp 32s that I ordered had a non functionnal antenna, which was really bad news because the whole project relied on communication between the controller and the slider, so I had to ditch the controller for now, to at least get the mechanical parts working.
Since I couldn't communicate with the pcb, I switched to an arduino uno with a cnc hat, that I had bought previously for a cnc project, that I haven't made yet, and got the 12v power from a power supply that I use for my rooms LED lighting.
I also had to splice the gt2 timing belt into a loop, which is not really meant to be done, but a custom loop this size is basically impossible to buy. so I glued them together and stiched them with nylon, and this holds properly, but the flexibility is gone, which is a problem when it gets into tight curves it can get stuck.



**Total time spent: 5h**

# July 4th, 2026: Building pt2

During the design phase, I used bolts that were non standard size, I tought, oh well, I'll figure it out on aliexpress later, and I never did, so I had about 16 m5 bolts to cut manually. I got out the hand saw, and the guide, and I got to work, it took about 5 minutes per screw, with the clean up after because the cuts were not smooth. For some other bolts were this was an option, I printed spacers and used longer screws. I also shortened the motor cables, because the space was limited, so I soldered them shorter, with some heat shrink tubes.
I inserted all of the heat set inserts inside the 3d printed parts, for the feets. I inserted all of the nuts, and added the wheels to the carriages. I then assembled the gt2 pulleys, and teethed pulleys to the motors and the gear assembly in the middle.
I also inserted the plastic holders into the bearings, and added them to the carriage.
I assembled the motors, and inserted the PCBs. Last thing was to put everything together, and test it.



**Total time spent: 2h**

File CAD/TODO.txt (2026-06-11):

TODO :
Start the BOM
add the 2 18650 batteries to the Controller CAD.
don't forget to add the voltage divider to the battery pins and the batteries

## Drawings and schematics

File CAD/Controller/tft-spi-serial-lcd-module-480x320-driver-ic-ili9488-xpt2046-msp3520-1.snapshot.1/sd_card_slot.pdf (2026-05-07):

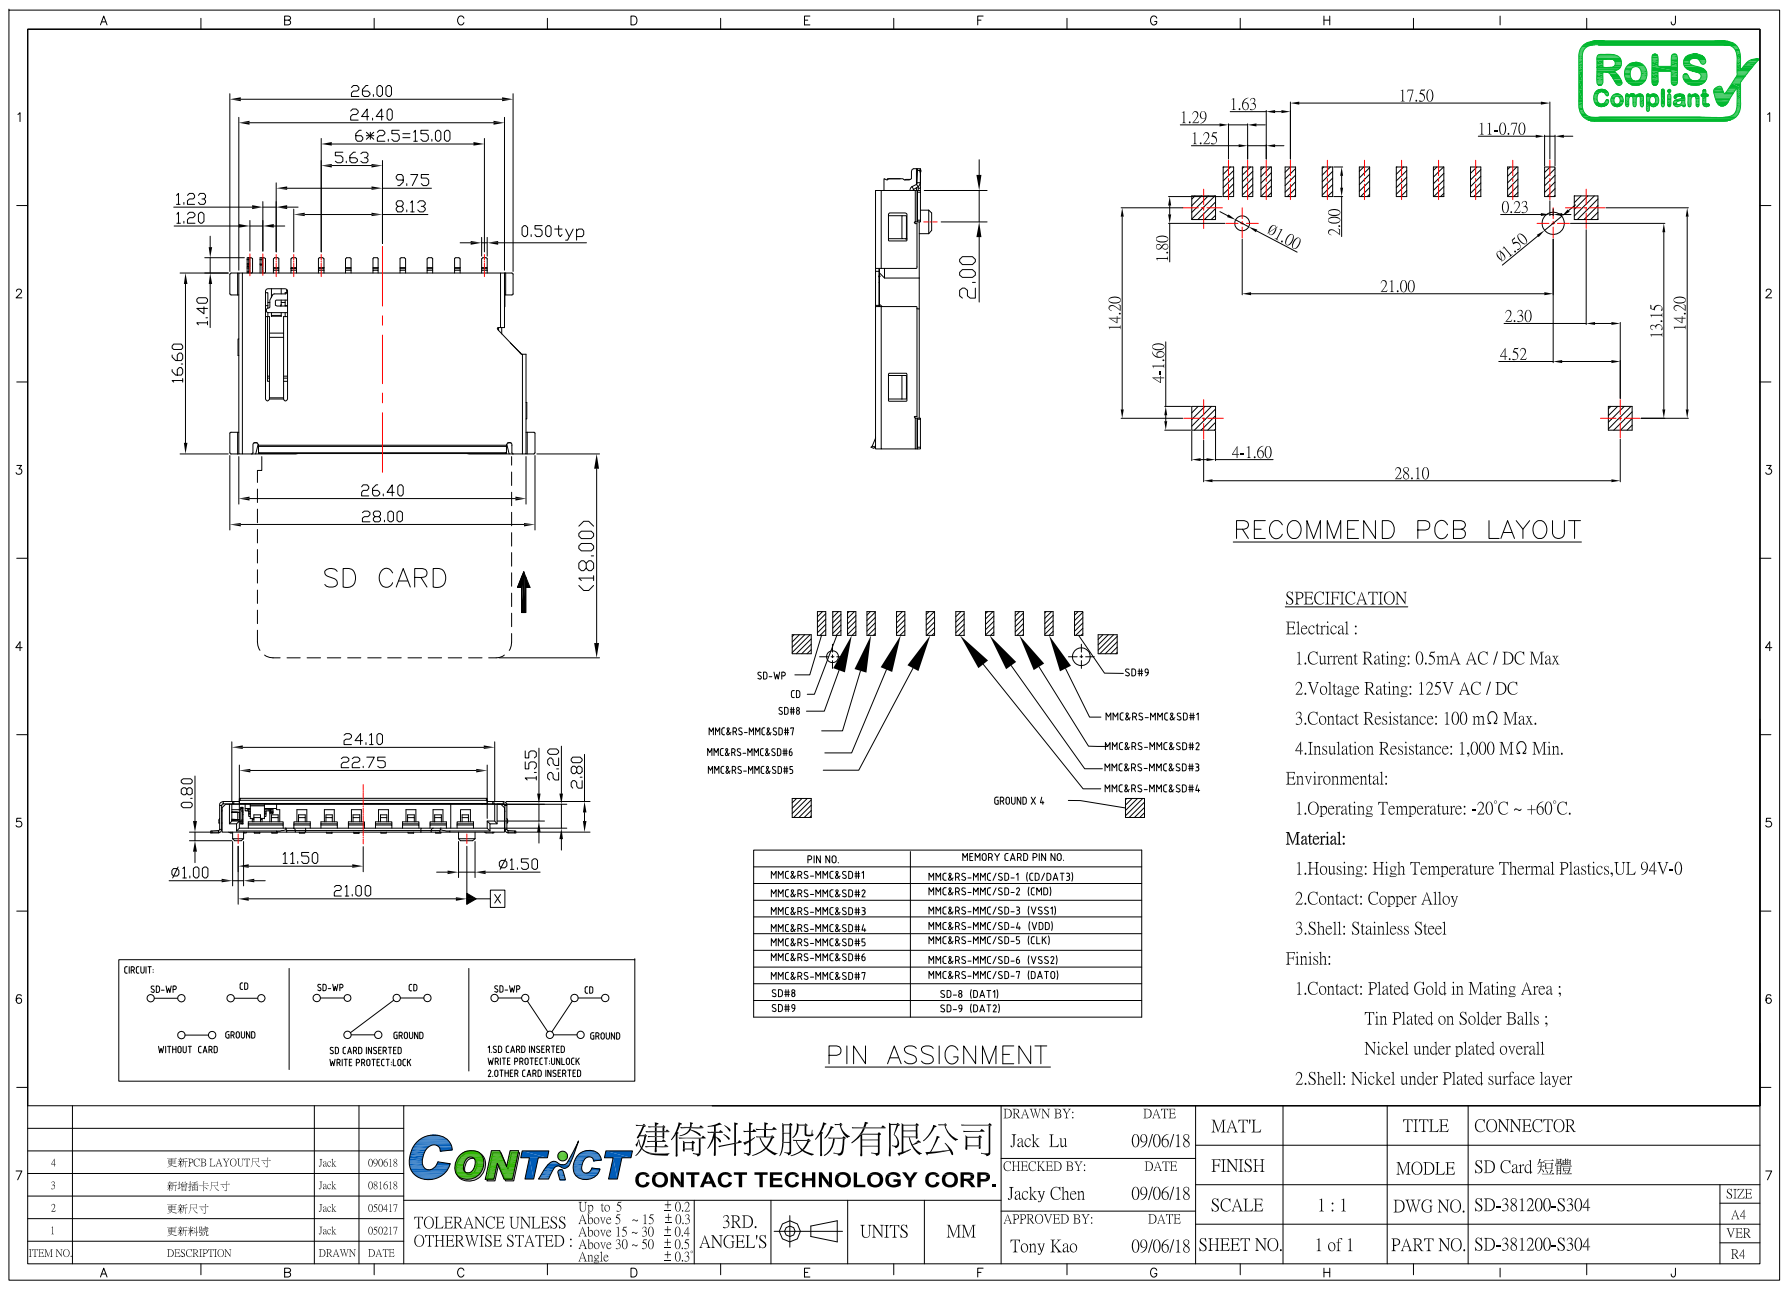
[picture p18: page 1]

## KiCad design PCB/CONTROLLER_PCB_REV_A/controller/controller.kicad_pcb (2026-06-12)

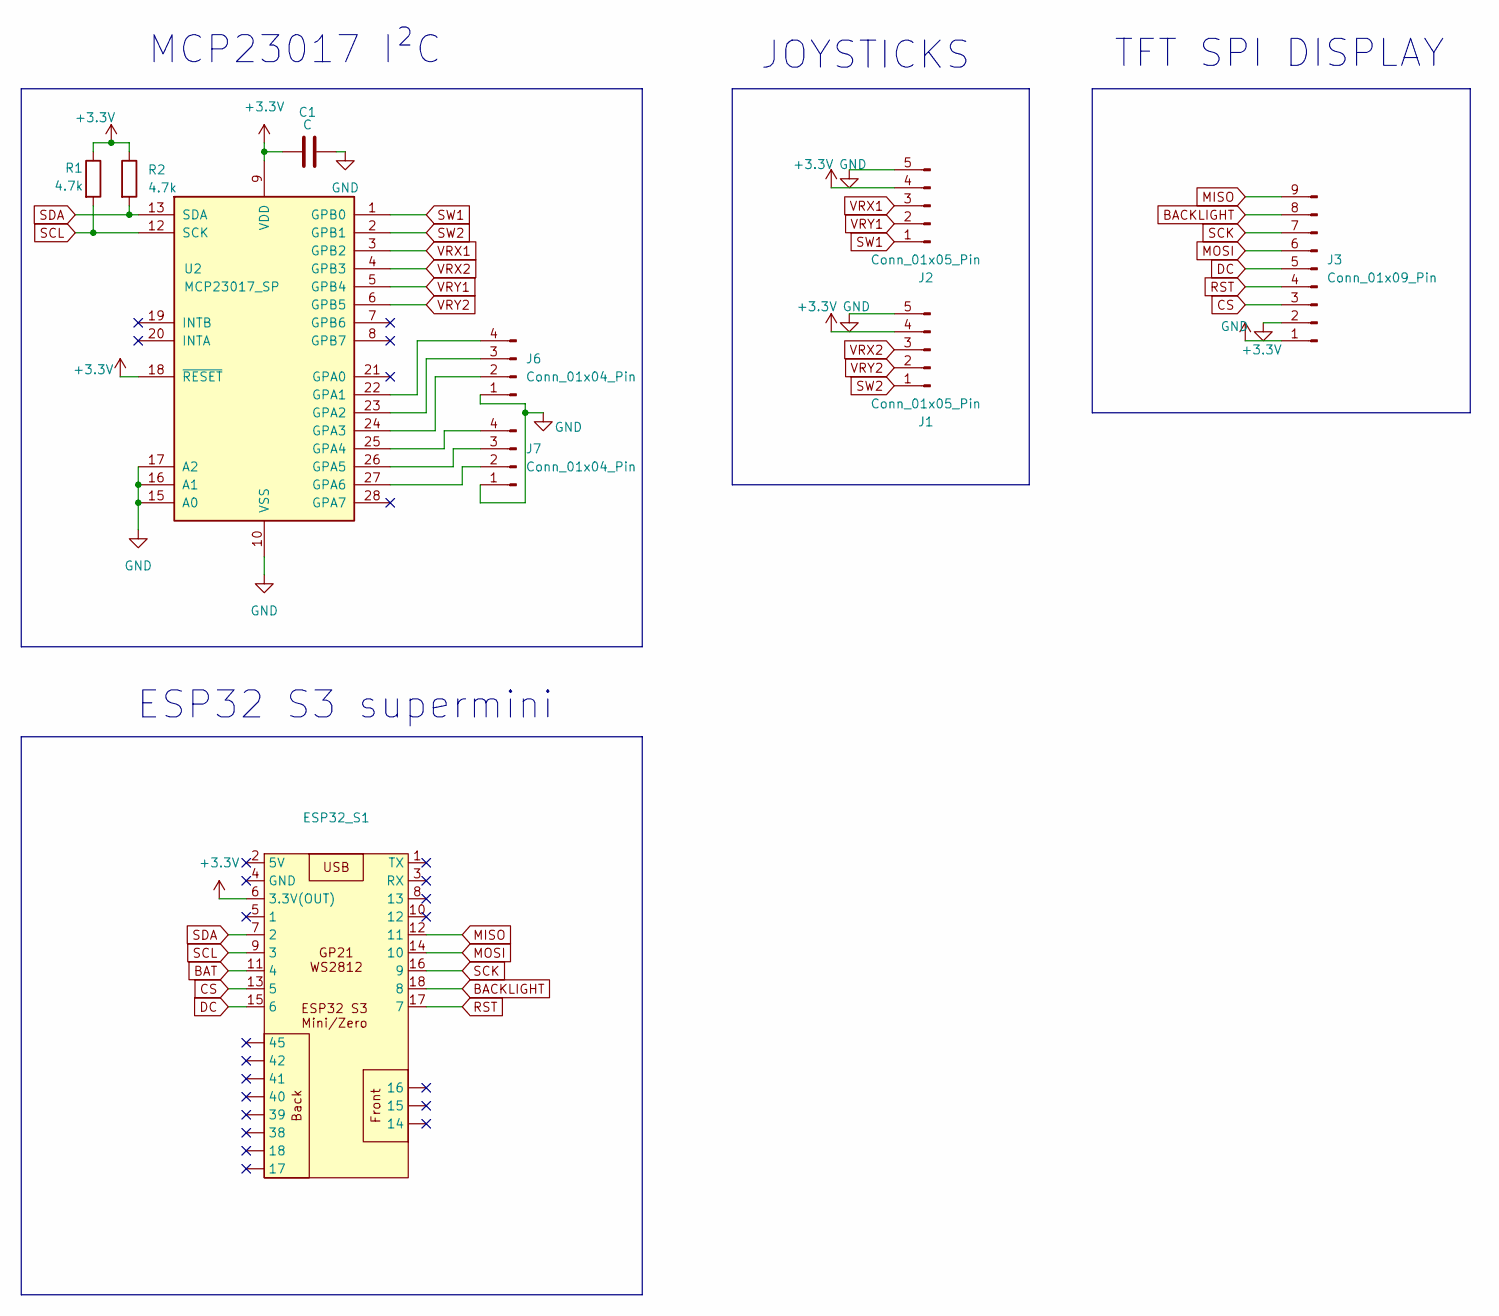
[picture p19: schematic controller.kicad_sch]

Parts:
C1: C; C_Disc_D5.0mm_W2.5mm_P5.00mm
ESP32_S1: ESP32-S3-MINI
J1, J2: Conn_01x05_Pin; PinHeader_1x05_P2.54mm_Vertical
J3: Conn_01x09_Pin; PinHeader_1x14_P2.54mm_Vertical
J6, J7: Conn_01x04_Pin; PinHeader_1x04_P2.54mm_Vertical
R1, R2: 4.7k; R_Axial_DIN0207_L6.3mm_D2.5mm_P7.62mm_Horizontal
U2: MCP23017_SP; DIP-28_W7.62mm

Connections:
+3.3V: C1.1, ESP32_S1.6 (3.3V(OUT)), J1.4, J2.4, J3.1, R1.1, R2.1, U2.9 (VDD), U2.18 (~RESET)
BACKLIGHT: ESP32_S1.18 (8), J3.8
BAT: ESP32_S1.11 (4)
CS: ESP32_S1.13 (5), J3.3
DC: ESP32_S1.15 (6), J3.5
GND: C1.2, J1.5, J2.5, J3.2, J6.1, J7.1, U2.10 (VSS), U2.15 (A0), U2.16 (A1), U2.17 (A2)
MISO: ESP32_S1.12 (11), J3.9
MOSI: ESP32_S1.14 (10), J3.6
unnamed: J6.2, U2.24 (GPA3)
unnamed: J6.3, U2.23 (GPA2)
unnamed: J6.4, U2.22 (GPA1)
unnamed: J7.2, U2.27 (GPA6)
unnamed: J7.3, U2.26 (GPA5)
unnamed: J7.4, U2.25 (GPA4)
RST: ESP32_S1.17 (7), J3.4
SCK: ESP32_S1.16 (9), J3.7
SCL: ESP32_S1.9 (3), R1.2, U2.12 (SCK)
SDA: ESP32_S1.7 (2), R2.2, U2.13 (SDA)
SW1: J2.1, U2.1 (GPB0)
SW2: J1.1, U2.2 (GPB1)
VRX1: J2.3, U2.3 (GPB2)
VRX2: J1.3, U2.4 (GPB3)
VRY1: J2.2, U2.5 (GPB4)
VRY2: J1.2, U2.6 (GPB5)

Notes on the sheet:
ESP32 S3 supermini
TFT SPI DISPLAY
JOYSTICKS
MCP23017 I²C

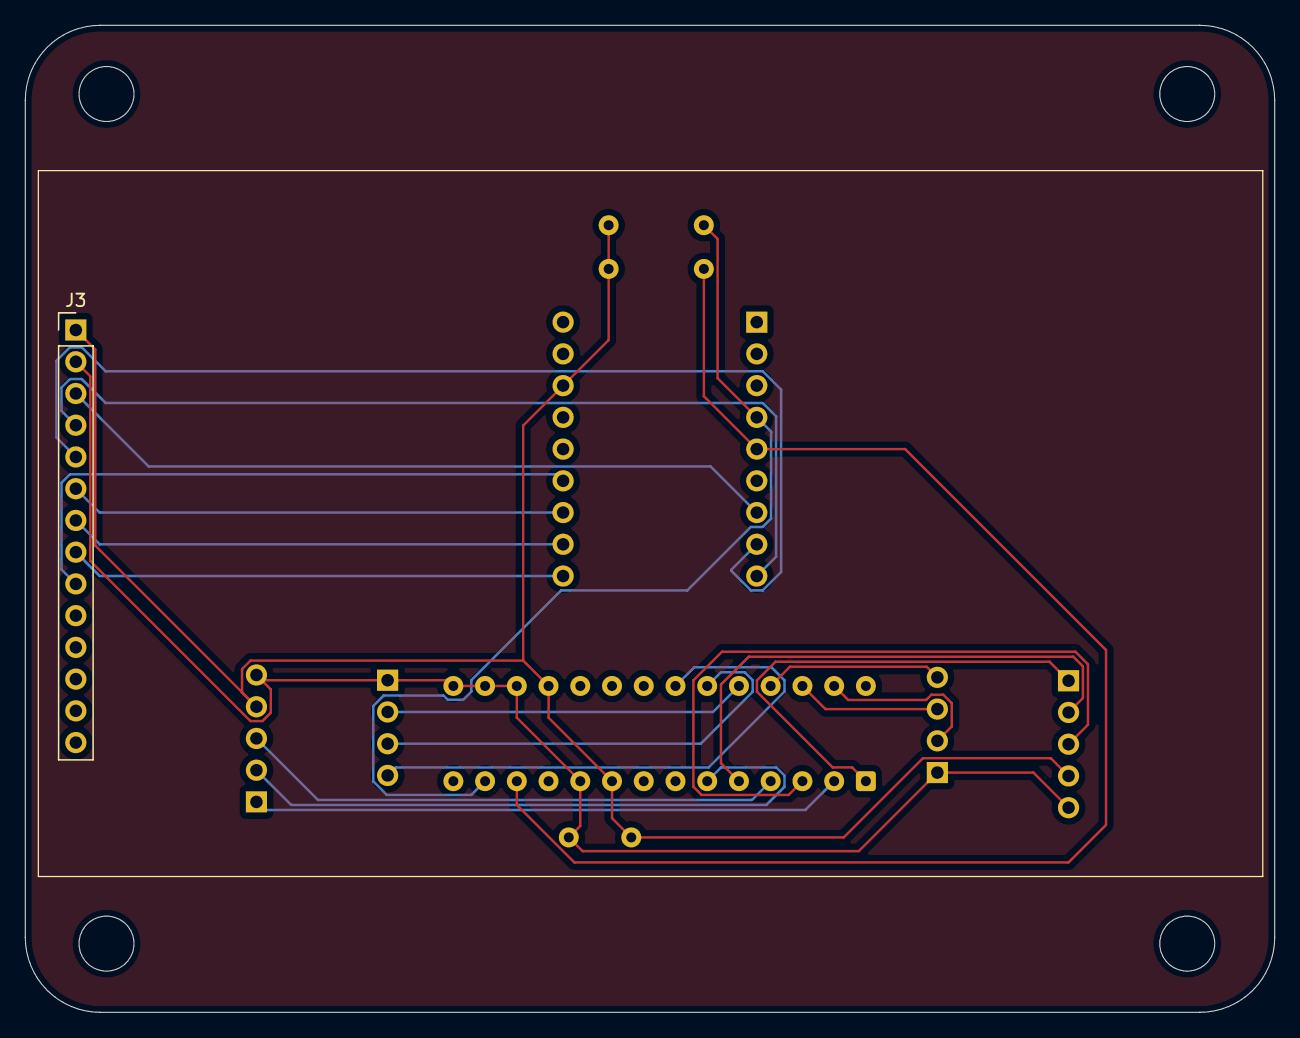
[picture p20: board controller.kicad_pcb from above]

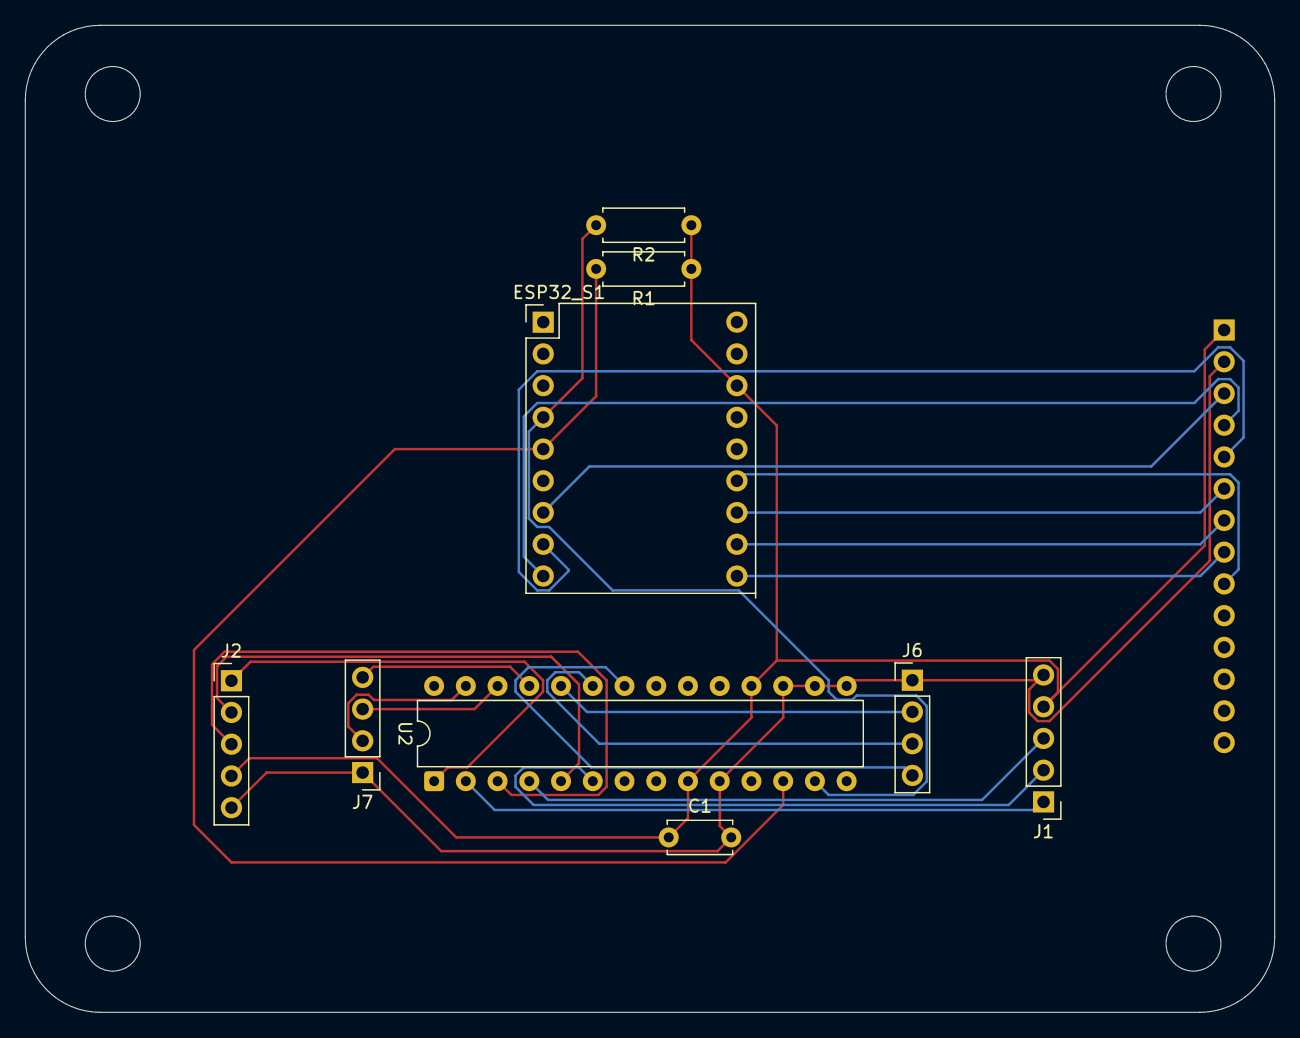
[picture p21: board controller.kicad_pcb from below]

Board: 2 copper layers, 100.0 x 79.0 mm, 10 parts (9 on the bottom side), 23 nets.

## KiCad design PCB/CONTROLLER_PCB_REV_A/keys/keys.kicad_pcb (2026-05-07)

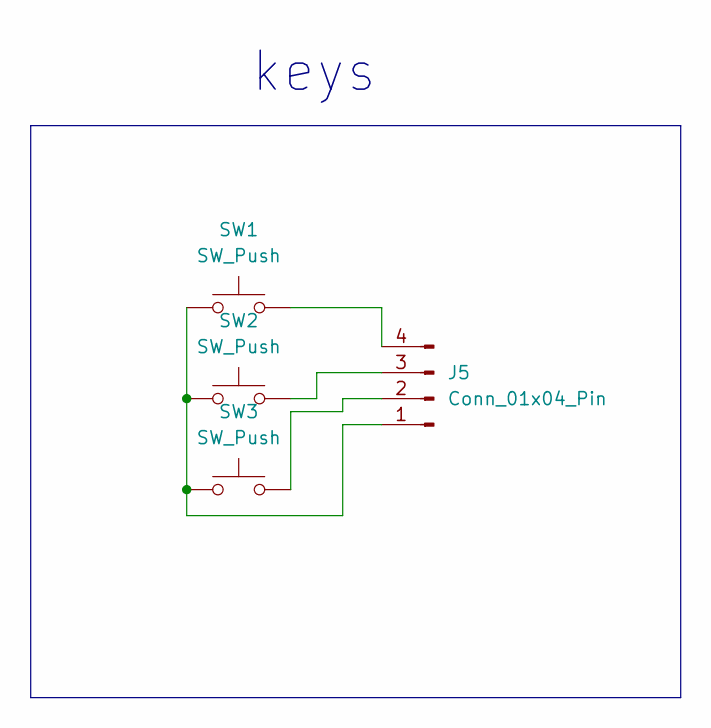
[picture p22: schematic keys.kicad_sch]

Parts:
J5: Conn_01x04_Pin; PinHeader_1x04_P2.54mm_Horizontal
SW1, SW2, SW3: SW_Push; SW_Cherry_MX_1.00u_PCB

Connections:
unnamed: J5.1, SW1.1, SW2.1, SW3.1
unnamed: J5.2, SW3.2
unnamed: J5.3, SW2.2
unnamed: J5.4, SW1.2

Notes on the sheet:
keys

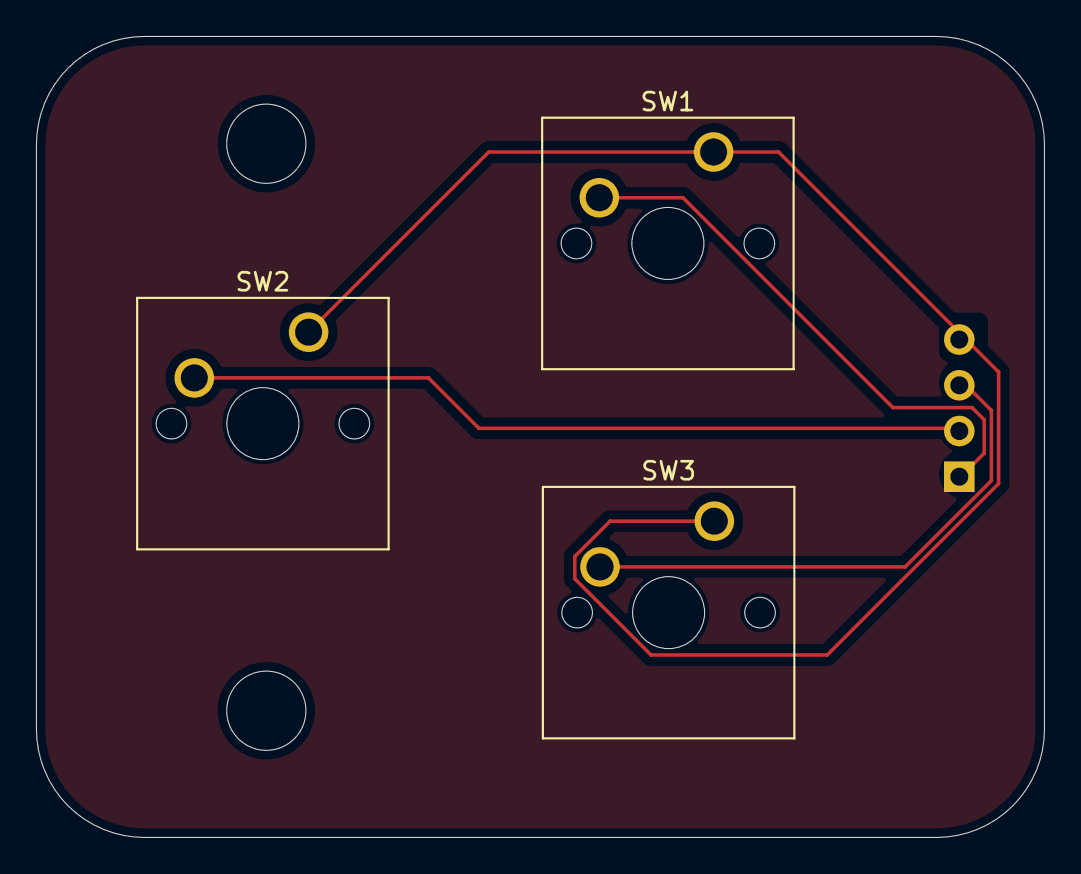
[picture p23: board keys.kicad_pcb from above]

Board: 2 copper layers, 56.0 x 44.5 mm, 4 parts (1 on the bottom side), 4 nets.

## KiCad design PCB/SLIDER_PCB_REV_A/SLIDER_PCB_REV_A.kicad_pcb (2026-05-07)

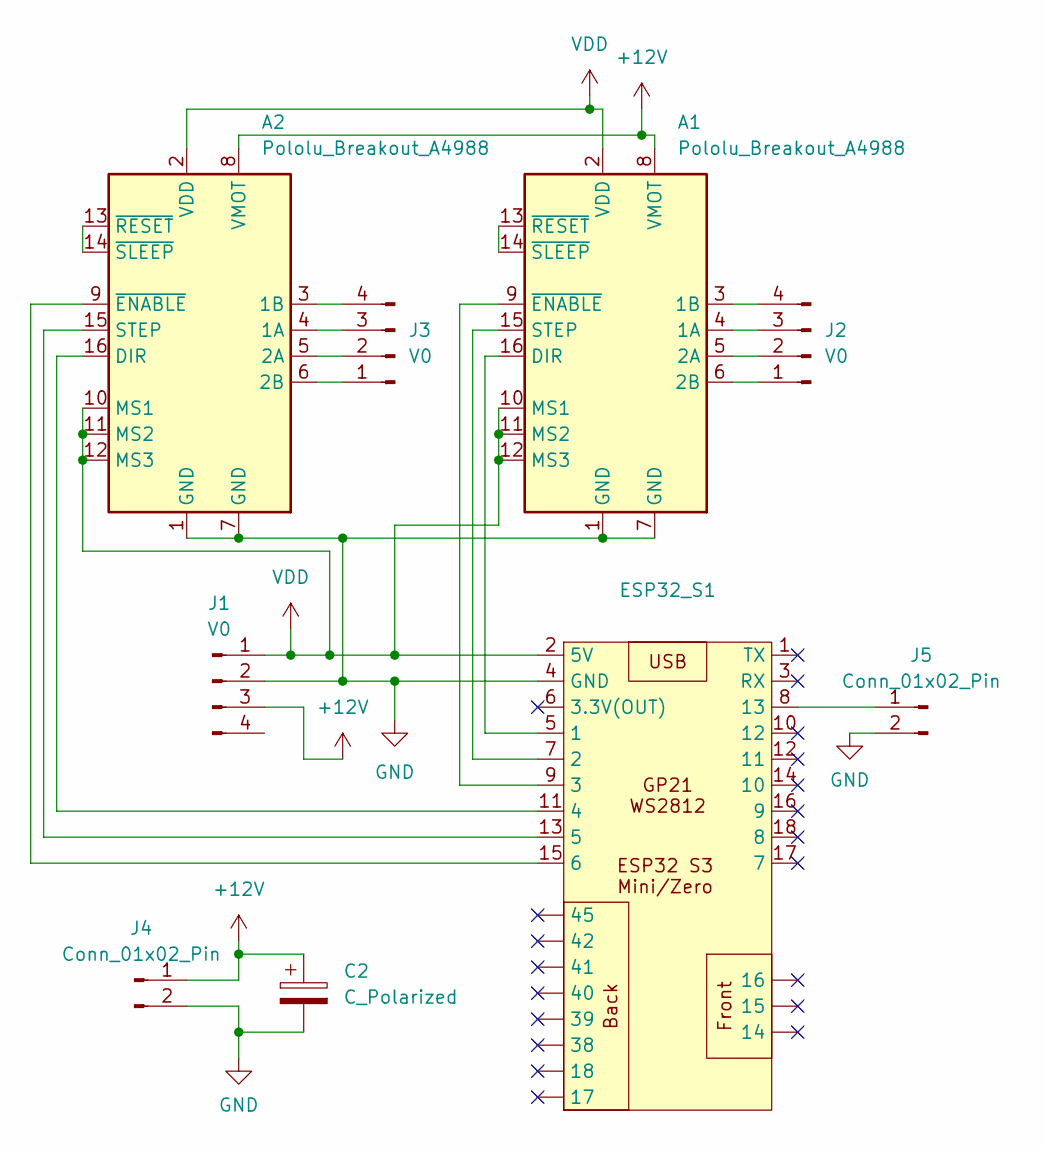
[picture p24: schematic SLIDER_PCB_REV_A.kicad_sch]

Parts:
A1, A2: Pololu_Breakout_A4988; Pololu_Breakout-16_15.2x20.3mm
C2: C_Polarized; C_Disc_D5.0mm_W2.5mm_P5.00mm
ESP32_S1: PinHeader_2x09_P2.54mm_Vertical
J1, J2, J3: V0; PinHeader_1x04_P2.54mm_Vertical
J4, J5: Conn_01x02_Pin; PinHeader_1x02_P2.54mm_Vertical

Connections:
+12V: A1.8 (VMOT), A2.8 (VMOT), C2.1, J1.3 (IN+), J4.1
GND: A1.1 (GND), A1.7 (GND), A2.1 (GND), A2.7 (GND), C2.2, ESP32_S1.4 (GND), J1.2 (GND), J4.2, J5.2
unnamed: A1.4 (1A), J2.3 (IN+)
unnamed: A1.3 (1B), J2.4 (EN)
unnamed: A1.5 (2A), J2.2 (GND)
unnamed: A1.6 (2B), J2.1 (V0)
unnamed: A1.16 (DIR), ESP32_S1.5 (1)
unnamed: A1.15 (STEP), ESP32_S1.7 (2)
unnamed: A1.9 (~ENABLE), ESP32_S1.9 (3)
unnamed: A1.13 (~RESET), A1.14 (~SLEEP)
unnamed: A2.4 (1A), J3.3 (IN+)
unnamed: A2.3 (1B), J3.4 (EN)
unnamed: A2.5 (2A), J3.2 (GND)
unnamed: A2.6 (2B), J3.1 (V0)
unnamed: A2.16 (DIR), ESP32_S1.11 (4)
unnamed: A2.15 (STEP), ESP32_S1.13 (5)
unnamed: A2.9 (~ENABLE), ESP32_S1.15 (6)
unnamed: A2.13 (~RESET), A2.14 (~SLEEP)
unnamed: ESP32_S1.8 (13), J5.1
VDD: A1.2 (VDD), A1.10 (MS1), A1.11 (MS2), A1.12 (MS3), A2.2 (VDD), A2.10 (MS1), A2.11 (MS2), A2.12 (MS3), ESP32_S1.2 (5V), J1.1 (V0)

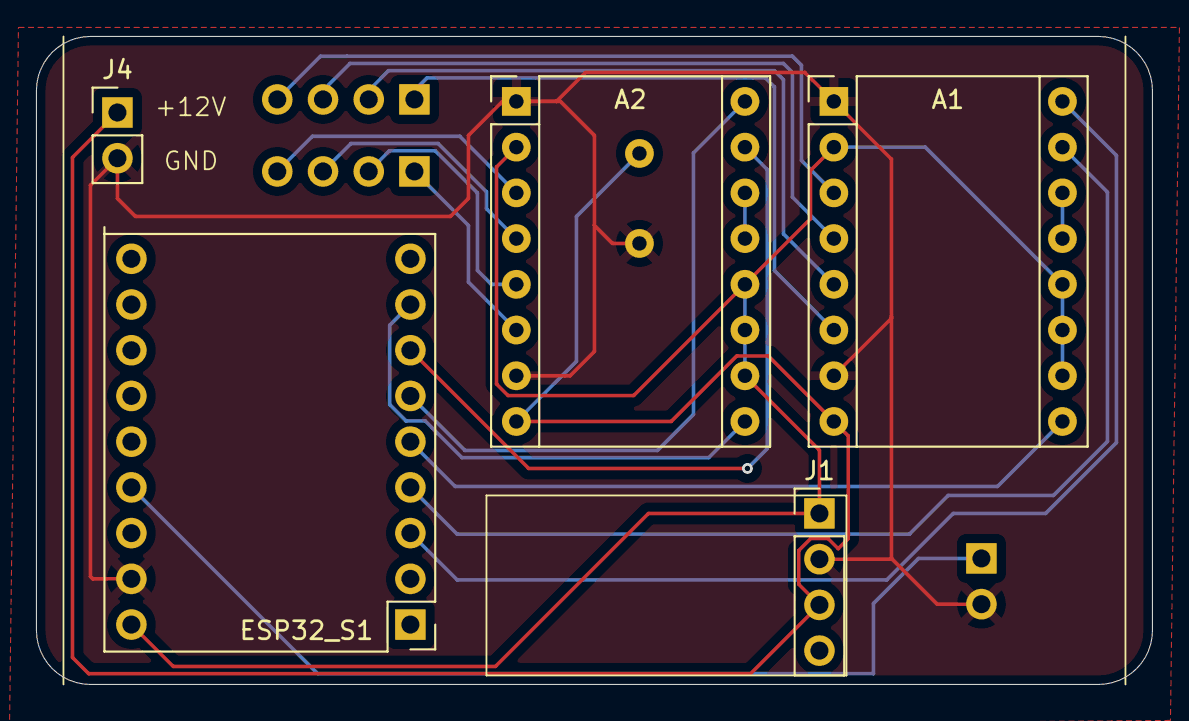
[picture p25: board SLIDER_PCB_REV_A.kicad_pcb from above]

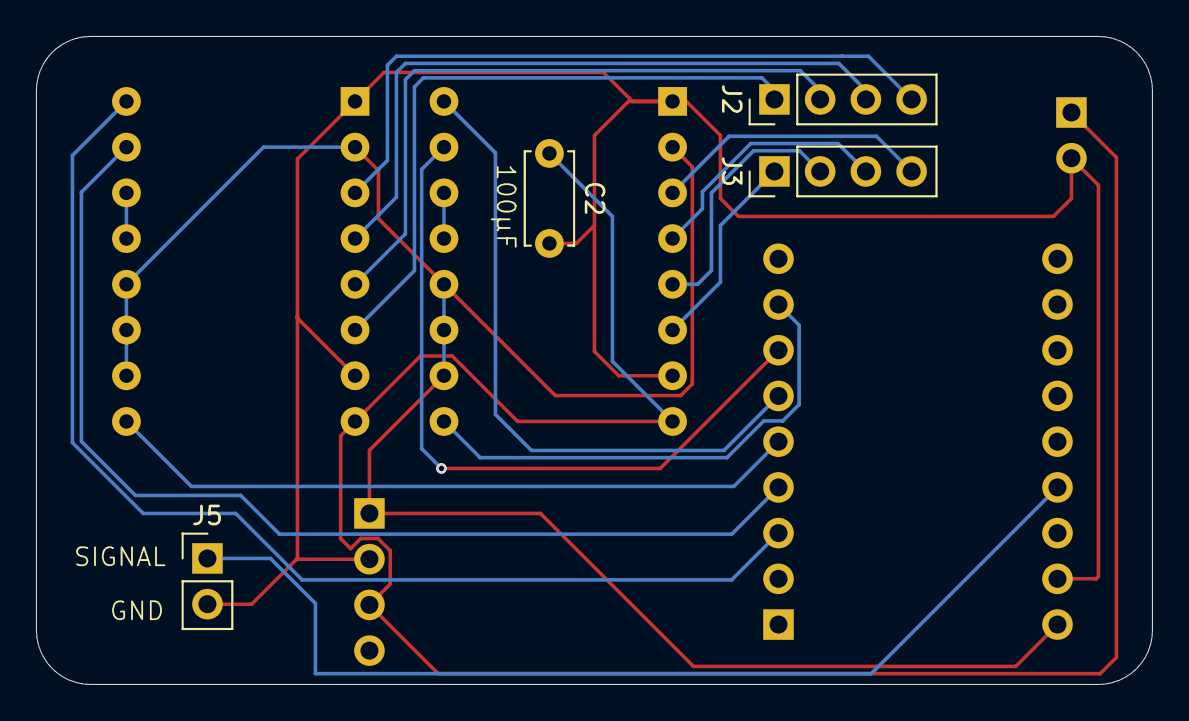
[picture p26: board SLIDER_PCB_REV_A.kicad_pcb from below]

Board: 2 copper layers, 62.0 x 36.0 mm, 9 parts (4 on the bottom side), 20 nets.

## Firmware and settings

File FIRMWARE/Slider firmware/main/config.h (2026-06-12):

#pragma once

// ============================================================
//  MotionCtrl – Global Pin & Config Definitions
//  Target: ESP32-S3, ESP-IDF v5.x
// ============================================================

// --- Motor 1 (A4988) ---
#define MOTOR1_DIR_PIN      GPIO_NUM_1
#define MOTOR1_STEP_PIN     GPIO_NUM_2
#define MOTOR1_ENABLE_PIN   GPIO_NUM_3

// --- Motor 2 (A4988) ---
#define MOTOR2_DIR_PIN      GPIO_NUM_4
#define MOTOR2_STEP_PIN     GPIO_NUM_5
#define MOTOR2_ENABLE_PIN   GPIO_NUM_6

// --- End Stop ---
#define ENDSTOP_PIN         GPIO_NUM_13   // LOW = pressed (connects to GND)

// --- UART for Controller Link (ESP32-S3 manette) ---
#define CTRL_UART_PORT      UART_NUM_1
#define CTRL_UART_TX        GPIO_NUM_17
#define CTRL_UART_RX        GPIO_NUM_18
#define CTRL_UART_BAUD      115200

// --- WiFi AP ---
#define WIFI_AP_SSID        "MotionCtrl"
#define WIFI_AP_PASS        "motionctrl123"
#define WIFI_AP_CHANNEL     6
#define WIFI_AP_MAX_STA     4

// --- Motion defaults ---
#define DEFAULT_STEPS_PER_MM    80        // adjust to your mechanics
#define DEFAULT_MAX_SPEED_MM_S  100.0f
#define DEFAULT_ACCEL_MM_S2     200.0f
#define MAX_SAVED_POINTS        32
#define MAX_SEQUENCE_STEPS      64

// --- NVS namespace ---
#define NVS_NAMESPACE           "motionctrl"

// --- WebSocket task ---
#define WS_BROADCAST_PERIOD_MS  100

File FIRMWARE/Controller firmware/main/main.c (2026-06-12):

// ============================================================
//  MotionCtrl – Handheld Controller Firmware
//  ESP32-S3 + 3.5" ILI9488 SPI display + joystick/buttons
//  Communicates with main unit via UART (framed JSON)
// ============================================================
//
//  Pin mapping (adjust to your PCB):
//    Display (SPI):
//      MOSI  = GPIO 11
//      SCLK  = GPIO 12
//      CS    = GPIO 10
//      DC    = GPIO 13
//      RST   = GPIO 14
//      BL    = GPIO 15 (backlight PWM)
//    Joystick 1 (Motor 1):
//      X     = GPIO 1  (ADC)
//      Y     = GPIO 2  (ADC, unused for now)
//      BTN   = GPIO 3
//    Joystick 2 (Motor 2):
//      X     = GPIO 4  (ADC)
//      Y     = GPIO 5  (ADC, unused)
//      BTN   = GPIO 6
//    Buttons:
//      STOP  = GPIO 7   (active LOW)
//      HOME  = GPIO 8
//      RUN   = GPIO 9
//      MENU  = GPIO 16
//    UART to main unit:
//      TX    = GPIO 17
//      RX    = GPIO 18
//
//  NOTE: Display driver uses esp_lcd (IDF v5+).
//        Replace ili9488_init() with your display driver if different.
// ============================================================

#include <stdio.h>
#include <string.h>
#include <math.h>
#include "freertos/FreeRTOS.h"
#include "freertos/task.h"
#include "freertos/queue.h"
#include "driver/gpio.h"
#include "driver/uart.h"
#include "driver/ledc.h"
#include "esp_adc/adc_oneshot.h"
#include "esp_log.h"
#include "esp_timer.h"
#include "nvs_flash.h"

static const char *TAG = "CTRL";

// -------------------------------------------------------
//  Pin definitions
// -------------------------------------------------------
#define DISP_MOSI     GPIO_NUM_11
#define DISP_SCLK     GPIO_NUM_12
#define DISP_CS       GPIO_NUM_10
#define DISP_DC       GPIO_NUM_13
#define DISP_RST      GPIO_NUM_14
#define DISP_BL       GPIO_NUM_15

#define JOY1_X_CH     ADC_CHANNEL_0   // GPIO 1
#define JOY2_X_CH     ADC_CHANNEL_3   // GPIO 4
#define JOY1_BTN      GPIO_NUM_3
#define JOY2_BTN      GPIO_NUM_6

#define BTN_STOP      GPIO_NUM_7
#define BTN_HOME      GPIO_NUM_8
#define BTN_RUN       GPIO_NUM_9
#define BTN_MENU      GPIO_NUM_16

#define UART_TX       GPIO_NUM_17
#define UART_RX       GPIO_NUM_18
#define UART_PORT     UART_NUM_1
#define UART_BAUD     115200

// -------------------------------------------------------
//  Protocol constants
// -------------------------------------------------------
#define STX  0x02
#define ETX  0x03

// -------------------------------------------------------
//  State
// -------------------------------------------------------
typedef enum { SCREEN_JOG=0, SCREEN_STATUS, SCREEN_POINTS, SCREEN_SEQ, SCREEN_COUNT } screen_t;
static screen_t current_screen = SCREEN_JOG;

typedef struct {
    int64_t m1_pos;
    int64_t m2_pos;
    char    state[16];
    bool    endstop;
    bool    m1_run;
    bool    m2_run;
} remote_status_t;

static remote_status_t remote = {0};

// -------------------------------------------------------
//  UART send
// -------------------------------------------------------
static void uart_send_cmd(const char *json)
{
    int len = strlen(json);
    uint8_t hdr[3] = { STX, (len>>8)&0xFF, len&0xFF };
    uart_write_bytes(UART_PORT, (char*)hdr, 3);
    uart_write_bytes(UART_PORT, json, len);
    uint8_t etx = ETX;
    uart_write_bytes(UART_PORT, (char*)&etx, 1);
}

// -------------------------------------------------------
//  Parse incoming status JSON from main unit
// -------------------------------------------------------
static void parse_status(const char *json)
{
    const char *p;
    p = strstr(json, "\"m1_pos\":");
    if (p) sscanf(p+9, "%lld", &remote.m1_pos);
    p = strstr(json, "\"m2_pos\":");
    if (p) sscanf(p+9, "%lld", &remote.m2_pos);
    p = strstr(json, "\"state\":\"");
    if (p) sscanf(p+9, "%15[^\"]", remote.state);
    p = strstr(json, "\"endstop\":");
    if (p) remote.endstop = (p[10] == 't');
    p = strstr(json, "\"m1_run\":");
    if (p) remote.m1_run = (p[9] == 't');
    p = strstr(json, "\"m2_run\":");
    if (p) remote.m2_run = (p[9] == 't');
}

// -------------------------------------------------------
//  UART RX task
// -------------------------------------------------------
static void uart_rx_task(void *arg)
{
    uint8_t buf[512], msg[512];
    int msg_pos=0; bool in_frame=false; int expected=0; int len_bytes=0;

    while (1) {
        int n = uart_read_bytes(UART_PORT, buf, sizeof(buf)-1, pdMS_TO_TICKS(20));
        for (int i=0; i<n; i++) {
            uint8_t b = buf[i];
            if (!in_frame) {
                if (b==STX) { in_frame=true; msg_pos=0; expected=0; len_bytes=0; }
            } else {
                if (len_bytes < 2) {
                    expected = (expected<<8)|b; len_bytes++;
                } else if (b == ETX) {
                    msg[msg_pos]=0;
                    parse_status((char*)msg);
                    in_frame=false;
                } else {
                    if (msg_pos < 511) msg[msg_pos++]=b;
                }
            }
        }
    }
}

// -------------------------------------------------------
//  ADC – joystick read  returns -100..+100
// -------------------------------------------------------
static adc_oneshot_unit_handle_t adc_handle;

static int read_joystick(adc_channel_t ch)
{
    int raw=0;
    adc_oneshot_read(adc_handle, ch, &raw);
    // 12-bit 0..4095, centre ~2048, deadband 200
    int v = raw - 2048;
    if (abs(v) < 200) return 0;
    return (v * 100) / 2048;
}

// -------------------------------------------------------
//  Button debounce
// -------------------------------------------------------
static bool btn_pressed(gpio_num_t pin)
{
    if (gpio_get_level(pin) == 0) {
        vTaskDelay(pdMS_TO_TICKS(20));
        return gpio_get_level(pin) == 0;
    }
    return false;
}

// -------------------------------------------------------
//  Simple display driver placeholder
//  Replace with your actual ILI9488 / ST7796 driver
// -------------------------------------------------------
// For production: use esp_lcd + lvgl or similar.
// This stub writes via bit-banging SPI and outputs to UART for debug.

static void display_init(void)
{
    // Configure backlight PWM
    ledc_timer_config_t lt = {
        .speed_mode      = LEDC_LOW_SPEED_MODE,
        .duty_resolution = LEDC_TIMER_8_BIT,
        .timer_num       = LEDC_TIMER_0,
        .freq_hz         = 5000,
        .clk_cfg         = LEDC_AUTO_CLK,
    };
    ledc_timer_config(&lt);
    ledc_channel_config_t lc = {
        .gpio_num   = DISP_BL,
        .speed_mode = LEDC_LOW_SPEED_MODE,
        .channel    = LEDC_CHANNEL_0,
        .timer_sel  = LEDC_TIMER_0,
        .duty       = 200,
        .hpoint     = 0,
    };
    ledc_channel_config(&lc);
    ESP_LOGI(TAG, "Display backlight on (stub – add ILI9488 driver for real output)");
}

// Print status to UART for debug (replace with real LCD draw calls)
static void display_render(void)
{
    static uint32_t frame = 0;
    if (frame++ % 20 != 0) return;  // ~2Hz refresh log

    ESP_LOGI(TAG, "┌──────────────────────────────┐");
    ESP_LOGI(TAG, "│ MotionCtrl    %-14s│", remote.state);
    ESP_LOGI(TAG, "│ M1: %-10lld  M2: %-10lld│", remote.m1_pos, remote.m2_pos);
    ESP_LOGI(TAG, "│ M1:%s  M2:%s  ES:%s     │",
             remote.m1_run?"RUN":"---",
             remote.m2_run?"RUN":"---",
             remote.endstop?"HIT":"---");
    ESP_LOGI(TAG, "│ Screen: %-21d│", current_screen);
    ESP_LOGI(TAG, "└──────────────────────────────┘");
}

// -------------------------------------------------------
//  Joystick jog task
// -------------------------------------------------------
#define JOG_DEADBAND     10    // percent
#define JOG_BASE_SPEED   5.0f  // mm/s at 100%
#define JOG_TICK_MS      100   // ms between jog commands

static void jog_task(void *arg)
{
    TickType_t last = xTaskGetTickCount();
    while (1) {
        vTaskDelayUntil(&last, pdMS_TO_TICKS(JOG_TICK_MS));

        int j1 = read_joystick(JOY1_X_CH);
        int j2 = read_joystick(JOY2_X_CH);

        if (abs(j1) > JOG_DEADBAND) {
            float speed = JOG_BASE_SPEED * (abs(j1) / 100.0f) * 4;
            int64_t steps = (j1 > 0 ? 1 : -1) * (int64_t)(abs(j1) / 10);
            char cmd[128];
            snprintf(cmd, sizeof(cmd),
                     "{\"cmd\":\"J\",\"motor\":0,\"steps\":%lld,\"speed\":%.1f}",
                     steps, speed);
            uart_send_cmd(cmd);
        }
        if (abs(j2) > JOG_DEADBAND) {
            float speed = JOG_BASE_SPEED * (abs(j2) / 100.0f) * 4;
            int64_t steps = (j2 > 0 ? 1 : -1) * (int64_t)(abs(j2) / 10);
            char cmd[128];
            snprintf(cmd, sizeof(cmd),
                     "{\"cmd\":\"J\",\"motor\":1,\"steps\":%lld,\"speed\":%.1f}",
                     steps, speed);
            uart_send_cmd(cmd);
        }
    }
}

// -------------------------------------------------------
//  Button scan task
// -------------------------------------------------------
static void btn_task(void *arg)
{
    while (1) {
        vTaskDelay(pdMS_TO_TICKS(50));

        if (btn_pressed(BTN_STOP)) {
            uart_send_cmd("{\"cmd\":\"S\"}");
            ESP_LOGW(TAG, "STOP");
            while (gpio_get_level(BTN_STOP)==0) vTaskDelay(pdMS_TO_TICKS(10));
        }

        if (btn_pressed(BTN_HOME)) {
            uart_send_cmd("{\"cmd\":\"H\",\"motor\":0}");
            ESP_LOGI(TAG, "HOME");
            while (gpio_get_level(BTN_HOME)==0) vTaskDelay(pdMS_TO_TICKS(10));
        }

        if (btn_pressed(BTN_RUN)) {
            uart_send_cmd("{\"cmd\":\"R\"}");
            ESP_LOGI(TAG, "RUN sequence");
            while (gpio_get_level(BTN_RUN)==0) vTaskDelay(pdMS_TO_TICKS(10));
        }

        if (btn_pressed(BTN_MENU)) {
            current_screen = (current_screen + 1) % SCREEN_COUNT;
            ESP_LOGI(TAG, "Screen -> %d", current_screen);
            while (gpio_get_level(BTN_MENU)==0) vTaskDelay(pdMS_TO_TICKS(10));
        }

        if (btn_pressed(JOY1_BTN)) {
            uart_send_cmd("{\"cmd\":\"P\"}");  // Pause/Resume toggle
            ESP_LOGI(TAG, "PAUSE");
            while (gpio_get_level(JOY1_BTN)==0) vTaskDelay(pdMS_TO_TICKS(10));
        }

        display_render();
    }
}

// -------------------------------------------------------
//  app_main
// -------------------------------------------------------
void app_main(void)
{
    ESP_LOGI(TAG, "Controller starting…");

    nvs_flash_init();

    // GPIO button pins
    gpio_num_t btns[] = {BTN_STOP, BTN_HOME, BTN_RUN, BTN_MENU, JOY1_BTN, JOY2_BTN};
    for (int i=0; i<6; i++) {
        gpio_config_t c = {
            .pin_bit_mask = 1ULL<<btns[i],
            .mode         = GPIO_MODE_INPUT,
            .pull_up_en   = GPIO_PULLUP_ENABLE,
        };
        gpio_config(&c);
    }

    // ADC for joysticks
    adc_oneshot_unit_init_cfg_t adc_cfg = { .unit_id = ADC_UNIT_1 };
    adc_oneshot_new_unit(&adc_cfg, &adc_handle);
    adc_oneshot_chan_cfg_t ch_cfg = { .atten=ADC_ATTEN_DB_12, .bitwidth=ADC_BITWIDTH_12 };
    adc_oneshot_config_channel(adc_handle, JOY1_X_CH, &ch_cfg);
    adc_oneshot_config_channel(adc_handle, JOY2_X_CH, &ch_cfg);

    // UART
    uart_config_t uc = {
        .baud_rate = UART_BAUD, .data_bits=UART_DATA_8_BITS,
        .parity=UART_PARITY_DISABLE, .stop_bits=UART_STOP_BITS_1,
        .flow_ctrl=UART_HW_FLOWCTRL_DISABLE,
    };
    uart_param_config(UART_PORT, &uc);
    uart_set_pin(UART_PORT, UART_TX, UART_RX, -1, -1);
    uart_driver_install(UART_PORT, 512, 512, 0, NULL, 0);

    // Display
    display_init();

    // Tasks
    xTaskCreate(uart_rx_task, "uart_rx", 4096, NULL, 5, NULL);
    xTaskCreate(jog_task,     "jog",     4096, NULL, 4, NULL);
    xTaskCreate(btn_task,     "btn",     4096, NULL, 3, NULL);

    ESP_LOGI(TAG, "Controller ready");
}

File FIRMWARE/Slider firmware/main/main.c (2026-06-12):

#include <stdio.h>
#include "freertos/FreeRTOS.h"
#include "freertos/task.h"
#include "nvs_flash.h"
#include "esp_log.h"
#include "driver/gpio.h"

#include "config.h"
#include "stepper.h"
#include "motion_planner.h"
#include "wifi_ap.h"
#include "webserver.h"
#include "controller_link.h"

static const char *TAG = "MAIN";

// -------------------------------------------------------
//  Endstop interrupt handler
// -------------------------------------------------------
static void IRAM_ATTR endstop_isr(void *arg)
{
    if (gpio_get_level(ENDSTOP_PIN) == 0) {
        // Triggered: emergency stop
        stepper_stop_all();
    }
}

// -------------------------------------------------------
//  Main
// -------------------------------------------------------
void app_main(void)
{
    ESP_LOGI(TAG, "MotionCtrl starting…");

    // ── NVS ──────────────────────────────────────────────
    esp_err_t ret = nvs_flash_init();
    if (ret == ESP_ERR_NVS_NO_FREE_PAGES ||
        ret == ESP_ERR_NVS_NEW_VERSION_FOUND) {
        nvs_flash_erase();
        nvs_flash_init();
    }

    // ── Steppers ─────────────────────────────────────────
    stepper_init();

    // ── Endstop interrupt ────────────────────────────────
    gpio_install_isr_service(0);
    gpio_isr_handler_add(ENDSTOP_PIN, endstop_isr, NULL);
    gpio_set_intr_type(ENDSTOP_PIN, GPIO_INTR_NEGEDGE);

    // ── Motion planner ───────────────────────────────────
    planner_init();

    // ── WiFi AP ──────────────────────────────────────────
    wifi_ap_init();

    // ── HTTP / WebSocket server ───────────────────────────
    webserver_init();

    // ── Controller link (UART to handheld) ───────────────
    controller_link_init();

    ESP_LOGI(TAG, "All systems up. Connect to WiFi '%s' → http://192.168.4.1",
             WIFI_AP_SSID);

    // ── Main loop (watchdog + status log) ────────────────
    while (1) {
        vTaskDelay(pdMS_TO_TICKS(5000));
        ESP_LOGI(TAG, "M1=%lld M2=%lld state=%d ES=%d",
                 stepper_get_position(MOTOR_1),
                 stepper_get_position(MOTOR_2),
                 (int)planner_get_state(),
                 gpio_get_level(ENDSTOP_PIN));
    }
}

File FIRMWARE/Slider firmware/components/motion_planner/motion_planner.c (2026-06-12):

#include "motion_planner.h"
#include "stepper.h"
#include "config.h"
#include "nvs_flash.h"
#include "nvs.h"
#include "esp_log.h"
#include "freertos/FreeRTOS.h"
#include "freertos/task.h"
#include "freertos/semphr.h"
#include <string.h>
#include <stdio.h>
#include <math.h>

static const char *TAG = "PLANNER";

// -------------------------------------------------------
//  State
// -------------------------------------------------------
static saved_point_t saved_points[MAX_SAVED_POINTS];
static int           point_count = 0;

static seq_step_t    sequence[MAX_SEQUENCE_STEPS];
static int           seq_count = 0;

static planner_state_t state = PLANNER_IDLE;
static SemaphoreHandle_t planner_mutex;
static TaskHandle_t      planner_task_handle = NULL;
static effect_config_t   active_effect;

// -------------------------------------------------------
//  Curve easing function  t ∈ [0,1] → position factor
// -------------------------------------------------------
static float ease(float t, curve_type_t curve)
{
    switch (curve) {
        case CURVE_LINEAR:    return t;
        case CURVE_EASE_IN:   return t * t;
        case CURVE_EASE_OUT:  return 1.0f - (1.0f - t) * (1.0f - t);
        case CURVE_EASE_BOTH: return t < 0.5f ? 2*t*t : 1-powf(-2*t+2,2)/2;
        case CURVE_BEZIER:    return t * t * (3 - 2*t);  // smooth step
        default:              return t;
    }
}

// Speed profile: peak speed reached at middle of move, eased at ends
static float speed_at_t(float t, float v_max, curve_type_t curve)
{
    float ramp = (t < 0.5f) ? ease(2*t, curve) : ease(2*(1-t), curve);
    return fmaxf(v_max * ramp, 1.0f);
}

// -------------------------------------------------------
//  Init
// -------------------------------------------------------
void planner_init(void)
{
    memset(saved_points, 0, sizeof(saved_points));
    memset(sequence, 0, sizeof(sequence));
    planner_mutex = xSemaphoreCreateMutex();
    planner_load_points_nvs();
    planner_load_sequence_nvs();
    ESP_LOGI(TAG, "Planner init done, %d points loaded", point_count);
}

// -------------------------------------------------------
//  Saved points
// -------------------------------------------------------
int planner_save_point(const char *name, int64_t m1, int64_t m2)
{
    xSemaphoreTake(planner_mutex, portMAX_DELAY);
    // Find existing by name or free slot
    int slot = -1;
    for (int i = 0; i < MAX_SAVED_POINTS; i++) {
        if (!saved_points[i].valid && slot == -1) slot = i;
        if (saved_points[i].valid && strcmp(saved_points[i].name, name) == 0) {
            slot = i; break;
        }
    }
    if (slot < 0) { xSemaphoreGive(planner_mutex); return -1; }
    strncpy(saved_points[slot].name, name, 31);
    saved_points[slot].pos_m1  = m1;
    saved_points[slot].pos_m2  = m2;
    saved_points[slot].valid   = true;
    if (slot >= point_count) point_count = slot + 1;
    xSemaphoreGive(planner_mutex);
    planner_save_points_nvs();
    return slot;
}

bool planner_delete_point(uint8_t idx)
{
    if (idx >= MAX_SAVED_POINTS) return false;
    xSemaphoreTake(planner_mutex, portMAX_DELAY);
    saved_points[idx].valid = false;
    xSemaphoreGive(planner_mutex);
    planner_save_points_nvs();
    return true;
}

bool planner_get_point(uint8_t idx, saved_point_t *out)
{
    if (idx >= MAX_SAVED_POINTS || !saved_points[idx].valid) return false;
    *out = saved_points[idx];
    return true;
}

int planner_get_point_count(void) { return point_count; }

// -------------------------------------------------------
//  NVS persistence
// -------------------------------------------------------
bool planner_save_points_nvs(void)
{
    nvs_handle_t h;
    if (nvs_open(NVS_NAMESPACE, NVS_READWRITE, &h) != ESP_OK) return false;
    nvs_set_blob(h, "points", saved_points, sizeof(saved_points));
    nvs_set_i32(h, "point_cnt", point_count);
    nvs_commit(h);
    nvs_close(h);
    return true;
}

bool planner_load_points_nvs(void)
{
    nvs_handle_t h;
    if (nvs_open(NVS_NAMESPACE, NVS_READONLY, &h) != ESP_OK) return false;
    size_t sz = sizeof(saved_points);
    nvs_get_blob(h, "points", saved_points, &sz);
    int32_t cnt = 0;
    nvs_get_i32(h, "point_cnt", &cnt);
    point_count = cnt;
    nvs_close(h);
    return true;
}

bool planner_save_sequence_nvs(void)
{
    nvs_handle_t h;
    if (nvs_open(NVS_NAMESPACE, NVS_READWRITE, &h) != ESP_OK) return false;
    nvs_set_blob(h, "sequence", sequence, sizeof(sequence));
    nvs_set_i32(h, "seq_cnt", seq_count);
    nvs_commit(h);
    nvs_close(h);
    return true;
}

bool planner_load_sequence_nvs(void)
{
    nvs_handle_t h;
    if (nvs_open(NVS_NAMESPACE, NVS_READONLY, &h) != ESP_OK) return false;
    size_t sz = sizeof(sequence);
    nvs_get_blob(h, "sequence", sequence, &sz);
    int32_t cnt = 0;
    nvs_get_i32(h, "seq_cnt", &cnt);
    seq_count = cnt;
    nvs_close(h);
    return true;
}

// -------------------------------------------------------
//  Sequence management
// -------------------------------------------------------
bool planner_seq_clear(void)
{
    memset(sequence, 0, sizeof(sequence));
    seq_count = 0;
    return true;
}

bool planner_seq_add_step(seq_step_t *step)
{
    if (seq_count >= MAX_SEQUENCE_STEPS) return false;
    sequence[seq_count++] = *step;
    planner_save_sequence_nvs();
    return true;
}

bool planner_seq_remove_step(uint8_t idx)
{
    if (idx >= seq_count) return false;
    memmove(&sequence[idx], &sequence[idx+1], (seq_count-idx-1)*sizeof(seq_step_t));
    seq_count--;
    planner_save_sequence_nvs();
    return true;
}

bool planner_seq_move_step(uint8_t from, uint8_t to)
{
    if (from >= seq_count || to >= seq_count) return false;
    seq_step_t tmp = sequence[from];
    memmove(&sequence[from], &sequence[from+1], (seq_count-from-1)*sizeof(seq_step_t));
    seq_count--;
    memmove(&sequence[to+1], &sequence[to], (seq_count-to)*sizeof(seq_step_t));
    sequence[to] = tmp;
    seq_count++;
    planner_save_sequence_nvs();
    return true;
}

int  planner_seq_get_count(void) { return seq_count; }

bool planner_seq_get_step(uint8_t idx, seq_step_t *out)
{
    if (idx >= seq_count) return false;
    *out = sequence[idx];
    return true;
}

// -------------------------------------------------------
//  Wait helpers
// -------------------------------------------------------
static void wait_motors_done(void)
{
    while ((stepper_is_running(MOTOR_1) || stepper_is_running(MOTOR_2)) &&
           state == PLANNER_RUNNING) {
        // Check for pause
        while (state == PLANNER_PAUSED) vTaskDelay(pdMS_TO_TICKS(50));
        vTaskDelay(pdMS_TO_TICKS(5));
    }
}

static void wait_s(float sec)
{
    int ms = (int)(sec * 1000);
    while (ms > 0 && state == PLANNER_RUNNING) {
        while (state == PLANNER_PAUSED) vTaskDelay(pdMS_TO_TICKS(50));
        vTaskDelay(pdMS_TO_TICKS(10));
        ms -= 10;
    }
}
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

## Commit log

2026-04-25 First commit, 18hrs of work; Only CAD and PCB.
    [SLIDER_PCB_REV_A.kicad_pcb, SLIDER_PCB_REV_A.kicad_sch, slider assembly.SLDASM]
2026-04-25 21h30 update : cad and PCB changes
    [SLIDER_PCB_REV_A.kicad_pcb, SLIDER_PCB_REV_A.kicad_sch, SLIDER_PCB_REV_A.step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]
2026-05-07 Added the whole controller PCB and CAD, plus some minor CAD changes, and a frog sticker asset for the controller.
    [Joystick HW504 Board.SLDPRT, PinHeader_1x04_P2.54mm_Vertical_3.step.SLDPRT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]
2026-05-07 Minor cad changes on the controller, added placeholder files in firmware, and moved some stuff around.
    [DSA 1u.step, DSA V4 1x1 v4_1.step.SLDASM, DSA V4 1x1 v4_2.step.SLDASM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]
2026-06-11 Added 3d print files, BOM, and other stuff
    [BOM.csv, Back cover.STEP, Battery holder.STEP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]
2026-06-12 Changed BOM Added 3mf project files for the 3d prints
    [BOM.csv, Controller prints project.3mf, Gear A.STEP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]
2026-06-12 added blender files added full step assemblies
    [Full controller assembly.STEP, Full slider assembly.STEP, Slider prints project.3mf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]
2026-06-12 Update README.md
    Added PCB buttons
2026-06-12 Updated firmware
    [controller.kicad_pcb, partitions.csv]
